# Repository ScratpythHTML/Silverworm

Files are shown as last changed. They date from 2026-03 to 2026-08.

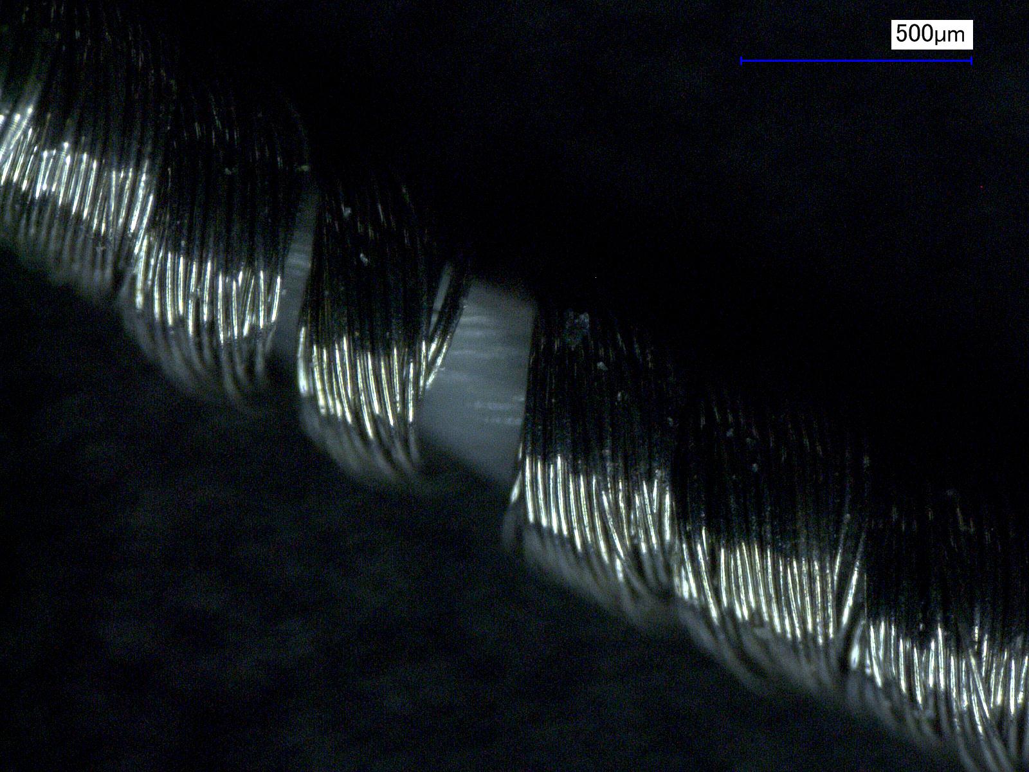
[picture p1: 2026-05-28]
image-processing/sample-images/Z150.jpg

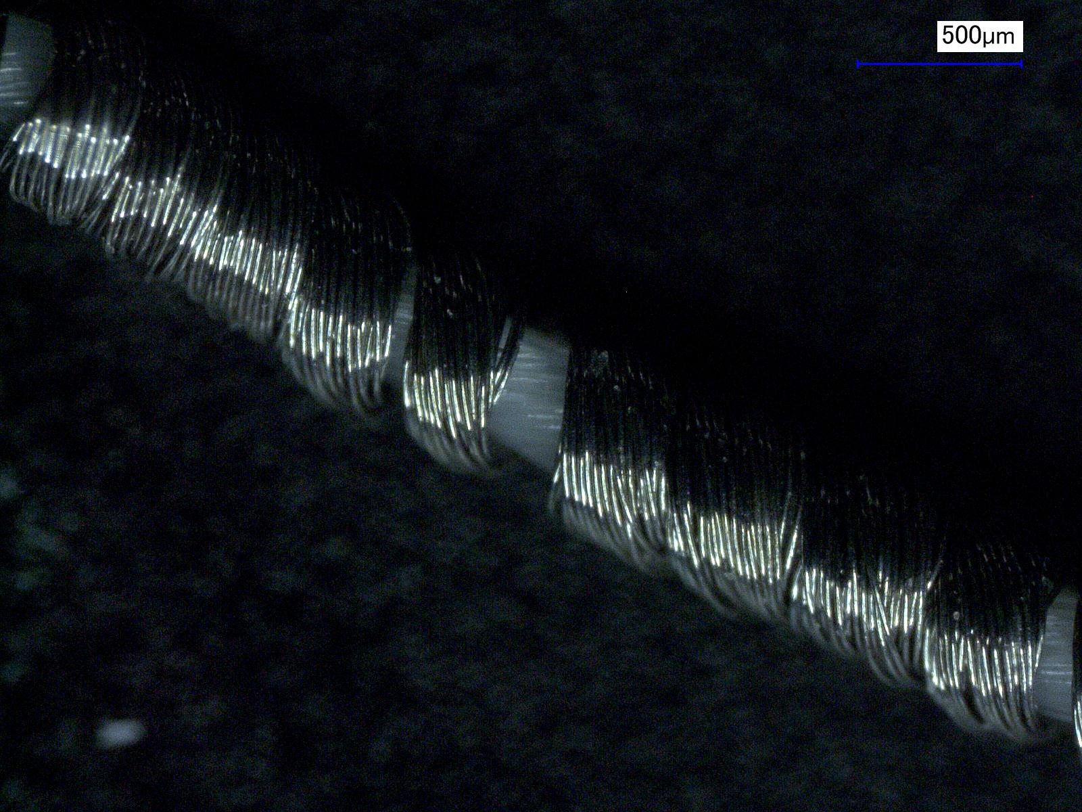
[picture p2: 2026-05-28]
image-processing/sample-images/Z100.jpg

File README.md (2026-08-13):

# Silverworm
Hardware and software design for the Silverworm spiral yarn wrapping machine.

## Group A
This is the wrapping team. We have designed a rotating arm that enscapulates a core yarn with a conductive outer fibre. The code in this repository is used to set the speed of the motor.

### Hardware
- Arduino Nano Every
- VNH5019 Motor Driver
- Honeywell Digital Hall Effect Sensor
- CHANCS 30W Permanent Magnet DC Motor 

### Software
The arduino code takes an inputted reference speed and accelerates the motor to this. It uses a Hall effect sensor and magnets on the arm to calculate the current speed. A PID controller is used for this system to eliminate error and ensure the motor willl get to the correct speed with in a set time. 

## Group B
This is the feeding. We have a feeding system that is passively tensioned which goes into team A's system; after the warpped yarn comes out, we collect it on a rotating collecting spool, which is on a linear rail to ensure orthodirectionality. 

### Hardware
- STM32
- DM423T Stepper Driver
- Linear Guide Rail with Nema 23 Stepper Motor
- oDrive S1 Motor Driver
- 24V 3000RPM 0.16Nm 50W 3.30A 42x42x62mm Brushless DC Motor ( with included hall effect sensor ) 
- 2 x Incremental Rotary Encoder IHC3808-001G-2000BZ1 ABZ 3-Channel 8mm Hollow Shaft

### Software
The code would take a inputted speed of the linear core yarn and then calculate the corresponding speeds that the linear rail and the BLDC motor would need to run at to ensure linear speed is accurate. The 2 encoders would give us both the radial velocity of the wrapper and the core yarn, allowing us to create a closed-loop control.

## Group C
This is the integration & control software — a PyQt6 app on a Raspberry Pi that reads the physical control panel, drives both motors, and measures yarn pitch live from a microscope camera.

### Hardware
- Raspberry Pi (Compute Module 5 + IO board)
- ESP32 physical UI panel — dials + mode/power switches (I2C)
- Wrap & feed motor controllers (SPI)
- AmScope HHD 8300-P USB microscope

### Software
The app is the system's central controller. It holds the machine state (mode, power, wrap + feed speeds), and the **physical panel is always the source of truth** — GUI controls are overwritten by the next dial/switch input. In AUTO it measures wrap pitch from the live camera and adjusts feed speed to hit the target; in MANUAL it overlays the target pitch/angle on the camera view for hand setup.

### Quick start

**On the wrapping machine (Raspberry Pi):**
```bash
python3 -m pip install -r interface/requirements-rpi.txt --break-system-packages
cd interface && python3 app.py
```

**On another computer (development, no hardware):**
```bash
python3 -m pip install -r interface/requirements.txt
cd interface && python3 app.py
```

On first launch you'll set target pitch, wire thickness, and tube diameter (tick "Remember settings" to skip it next time). With no panel attached, use the **Debug** menu to simulate dial/switch input.

### Code files
```
interface/
  app.py             Launcher — startup dialog → main window
  ui/main_window.py  Wires UI + state + hardware together
  app_state.py       Central state (mode/power/speeds), routes motor commands
  config.py          Settings, JSON persistence, wrap-angle math
  pitch_control.py   Closed-loop pitch → feed-speed control
  telemetry.py       Per-command timing/telemetry for the test report
  storage.py         Atomic saves (snapshots, recordings, logs)
  hardware.py        Picks real vs mock I2C/SPI transports per platform
  comms/
    pui.py           ESP32 panel protocol (I2C parser + listener)
    motor_spi.py     Arduino motor protocol (SPI packet codec)
  camera/            AmScope detection, capture, rolling frame buffer
  processing/
    pipeline.py      Runs pitch estimation on live camera frames
  ui/                GUI widgets (camera view, controls, graphs, dialogs)
  hil_test.py        Hardware-in-the-loop harness (no camera needed)
  diagnose.py        Environment / setup checker
image-processing/
  pitch_estimate.py  CV pitch measurement (OpenCV + SciPy)
```

### Continuing development
Start at `app.py` → `ui/main_window.py` → `app_state.py` (the central state machine). The reference sections below cover the protocols, formulas, and extension recipes you need to add features or bring up new hardware.

## How it works (reference)

### Architecture
```
ESP32 (panel) ──I2C──► Raspberry Pi (this app) ──SPI──► Arduino (motors)
 dials/switches          PyQt6 GUI + vision            wrap + feed
                         AppState = source of truth
```
The **physical panel always wins**: any dial/switch event overwrites what the GUI set. The GUI is a display/backup.

### Communication protocols
**I2C — panel → Pi (ASCII):**

| Message | Meaning |
|---|---|
| `D1±N` | Dial 1 (wrap) ± N detents, N∈{1,2,3} = small/med/large |
| `D2±N` | Dial 2 (feed) ± N detents |
| `AS0` / `AS1` | Mode → MANUAL / AUTO |
| `TP` | Toggle machine power |

Dials send *increments*, not absolute values; the detent→units lookup is in `DetentConfig` (`config.py`).

**SPI — Pi → Arduino (byte packets):**

| Prefix | Command | Payload |
|---|---|---|
| `0x01` | Start | speedL, speedH (uint16 LE) |
| `0x02` | Stop | stop_type (1=ramp, 2=emergency, 3=power-off) |
| `0x03` | Set speed | speedL, speedH |
| `0x04` | Test movement | movement_type |
| `0x05` | Request speed | — |

**SPI — Arduino → Pi:** `0x01` current speed · `0x02` error_code · `0x03` sequence status.

### Core formulas
```python
theta = arctan(pitch / (pi * (tube_diameter + 2 * wire_thickness)))  # wrap angle
pitches_um = np.diff(peak_positions_px) * um_per_px                   # pitch from peaks
cv = std_pitch / mean_pitch                                          # confidence:
#   HIGH if wraps>=10 and cv<0.20 ; MEDIUM if wraps>=5 and cv<0.35 ; else LOW
```

### Settings
Persisted to the OS config dir, loaded on startup (target pitch, wire thickness, tube diameter, detent→speed mappings, remember-settings): macOS `~/Library/Preferences/Silverworm/config.json`, Linux `~/.config/Silverworm/config.json`. The manual-mode GUI toggle is hidden by default (enable in Settings with the warning ack) to avoid PUI/GUI desync.

## Extending the app
- **New PUI message:** add a case in `parse_pui_message()` + a dataclass (`comms/pui.py`) → signal on `PUIListener` → `apply_*` handler on `AppState` → wire in `MainWindow._connect_app_state_signals()` → test in `tests/test_pui_protocol.py` + `tests/test_app_state.py`.
- **New motor command:** add to `CommandPrefix` + `build_<cmd>()` with bounds checks (`comms/motor_spi.py`) → method on `MotorController` → test in `tests/test_motor_spi.py`.
- **Tune pitch detection:** edit `image-processing/pitch_estimate.py` (`min_dist_px`, `sigma`, `prom_factor`).

## Testing
```bash
cd interface
pytest -q tests/test_pui_protocol.py tests/test_motor_spi.py tests/test_app_state.py
```
The protocol layer is fully tested without hardware via `MockPUITransport` / `MockSPITransport`. Camera/UI tests need Linux + `pytest-qt`.

## Repository map
Several subfolders have their own README with hardware-specific detail (pin maps, wiring, board files). Start here, then drill in:

| Folder | Contents |
|---|---|
| [interface/](interface/) | Group C control software (see above) |
| [image-processing/](image-processing/) | Pitch-measurement CV pipeline |
| [GroupA/](GroupA/) | Group A wrapper-motor firmware (Arduino Nano Every) |
| [GroupB/](GroupB/README.md) | Group B collecting firmware + Uno pin map |
| [IO Panel/](IO%20Panel/Silverworm_Control_Panel/README.md) | ESP32 panel pinout + I2C protocol |
| → [Web test tool](IO%20Panel/Silverworm_Control_Panel/IO%20Panel%20Software/Web_Test_Version/README.md) | Browser serial test UI for the panel |
| [Motherboard/Hardware/](Motherboard/Hardware/Silverworm%20-%20CM5%20Motherboard/) | CM5 carrier-board KiCAD files |
| [Motherboard/Software/](Motherboard/Software/README.md) | Enabling SPI/I2C on the CM5 |
| [Subsystem Interfacing/](Subsystem%20Interfacing/README.md) | Cross-board SPI wiring overview |

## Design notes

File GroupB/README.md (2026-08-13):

# Collecting-system firmware (Arduino Uno R2)

For **STM32CubeIDE** (bare metal), see `[stm32/motors/README.md](../../stm32/motors/README.md)`.

Target board: **Arduino Uno R2** (ATmega328P).

| Subsystem | Hardware | Interface |
| --- | --- | --- |
| Linear rail | FSK40J + NEMA 23 + **DM423T** | STEP / DIR / ENA → D2–D4 |
| Collecting spool | 42BSA62 + **oDrive S1** | UART → D8–D9; encoder **#1** on oDrive ENC0 |
| Line / roller shaft | IHC3808 encoder **#2** | Quadrature A/B/(Z) → D5–D7 |
| Supervisor | Raspberry Pi | SPI slave → D10–D13 |

No USB serial commands in production — control is **SPI only** (`SpiProtocol.h`).

## Uno pin map (ATmega328P)

| Arduino pin | ATmega328P port | Function |
| --- | --- | --- |
| D2 | PD2 | Linear STEP → DM423T PUL+ |
| D3 | PD3 | Linear DIR → DM423T DIR+ |
| D4 | PD4 | Linear ENA → DM423T ENA+ |
| D5 | PD5 | Encoder #2 A |
| D6 | PD6 | Encoder #2 B |
| D7 | PD7 | Encoder #2 Z (index, optional) |
| D8 | PB0 | oDrive UART RX ← oDrive TX |
| D9 | PB1 | oDrive UART TX → oDrive RX |
| D10 | PB2 | SPI SS (CS) ← Pi |
| D11 | PB3 | SPI MOSI ← Pi |
| D12 | PB4 | SPI MISO → Pi |
| D13 | PB5 | SPI SCK ← Pi |
| A0 | PC0 | Limit switch min (optional) |
| A1 | PC1 | Limit switch max (optional) |

DM423T **PUL−, DIR−, ENA−** → Arduino **GND**.

`config.h` uses Arduino pin numbers (`2`–`13`, `A0`/`A1`) as on the Uno.

## Power and grounds

- **24 V** → DM423T and oDrive motor supply (common GND).
- **5 V** → DM423T logic (if required), oDrive `ISO_VDD` (set logic level per [oDrive UART docs](https://docs.odriverobotics.com/v/latest/manual/uart.html)).
- Uno I/O is **5 V**. Level-shift SPI and UART to the Pi and oDrive if those interfaces expect 3.3 V.
- **Pi GND** ↔ Arduino GND.

## oDrive setup (ODrive Tool / Web GUI)

Before relying on firmware:

1. Motor phases → oDrive; **incremental encoder #1** on **ENC0** (A, B, Z).
2. Set `inc_encoder0.config.cpr` (typically **8000** for 2000 PPR quadrature).
3. Run encoder calibration and closed-loop test.
4. Enable UART A at `**ODRIVE_BAUD` (19200)**. Firmware uses **SoftwareSerial** on D8/D9 — the Uno has only one hardware UART (D0/D1, used by USB serial). To use hardware Serial instead, rewire to D0/D1 and switch `BldcMotor` to `HardwareSerial` (Serial).
5. Match GPIO UART pins on the S1 to your harness.
6. Optional: save `vel_ramp_rate` in the GUI if you tune ramping there — firmware also sets **velocity ramp** (`INPUT_MODE_VEL_RAMP`) at boot to match `SPI_SPEED_RAMP_RPM_S` in `config.h`.

Firmware uses the **[ODriveArduino](https://docs.odriverobotics.com/v/latest/guides/arduino-uart-guide.html)** library (`ODriveUART`: `setVelocity`, `getFeedback`, `clearErrors`, closed-loop state).

## Encoder #2

Counted in firmware via GPIO interrupts on D5 and D6 (PD5, PD6). `lineEncoder.rpm()` is updated in `poll()` for local use (ratio / monitoring). SPI telemetry prefix `'1'` still reports **spool** RPM from oDrive feedback.

Set `ENC2_CPR` in `config.h` to match the IHC3808 datasheet.

## SPI protocol

See `SpiProtocol.h` and the transaction rules in the previous sections of this README.

Outbound priority: **error** > **sequence ack** > **live spool speed**.

## Build

1. Install the **Arduino IDE** (2.x recommended) with the standard **Arduino AVR Boards** package.
2. Install **ODriveArduino**: *Sketch → Include Library → Manage Libraries* → "ODriveArduino".
3. Open `motors.ino`.
4. Board: **Arduino Uno** (Tools → Board → Arduino AVR Boards → Arduino Uno).
5. Edit `config.h` (stroke, CPR, limits).
6. Upload via USB.

## Calibration

1. Set `LINEAR_STROKE_MM_DEFAULT` to your FSK40J stroke.
2. Home linear axis (limits on A0/A1 when wired).
3. Confirm oDrive enters closed loop and spool feedback RPM matches direction before coupling yarn.

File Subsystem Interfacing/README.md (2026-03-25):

## SPI Protocol outline:



## SPI for Raspberry Pi:
Motherboard runs as Master
See Motherboard section.

## SPI on microcontrollers
The microcontrollers are set as slaves.

Read this guide for info: https://www.circuitbasics.com/how-to-set-up-spi-communication-for-arduino/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,to%20send%20or%20receive%20data.

Here are the docs for the `SPI.h` Arduino library: https://docs.arduino.cc/language-reference/en/functions/communication/SPI/

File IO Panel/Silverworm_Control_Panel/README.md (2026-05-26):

# UI Panel Pinout

| Pin | Use | Mode |
|---|---|---|
| GPIO 0  | LED1-R | ANALOG OUT |
| GPIO 1  | LED1-G | ANALOG OUT |
| GPIO 2  | LED1-B | ANALOG OUT |
| GPIO 3  | TOGGLE | DIG INPUT |
| GPIO 13 | BTN2_LED | NOT USED |
| GPIO 14 | BTN_1LED | DIGITAL OUT  |
| GPIO 4  | BTN2 | NOT USED |
| GPIO 5  | BTN1 | INPUT PULLUP |
| GPIO 24 | DIAL1A | DIG INPUT |
| GPIO 23 | DIAL1B | DIG INPUT |
| GPIO 10 | DIAL1NO  | INPUT PULLUP |
| GPIO 11 | DIAL2A | DIG INPUT |
| GPIO 25 | DIAL2B | DIG INPUT |
| GPIO 12 | DIAL2NO  | INPUT PULLUP |
| GPIO 8  | SDA | SDA |
| GPIO 22 | SCL | SCL |
| GPIO 9  | LED2-R | ANALOG OUT |
| GPIO 27 | LED2-G | ANALOG OUT |
| GPIO 26 | LED2-B | ANALOG OUT |

# UI Panel Communications Protocol:

Uses I2C for communications between the ESP32 and the RPi

On the RPi side, we are using pins:
GPIO10 for SDA
GPIO11 for SCL

## I2C Functions for Communication:

The ESP32 sends the change in speeds for the motors, which the Raspberry Pi then applies to the variables within the backend which store the target motor speeds

### For Dials:
The ESP32 sends the label `D1` or `D2` before every command to identify dials 1 and 2
Then the number that it increments by:
- Small detent gives a `+1` or `-1`
- Medium detent gives `+2` or `-2`
- Large detent gives `+3` or `-3`

_For example: `D1-2` or `D2+1`_

So the ESP32 tells the RPi _which_ detent option is being used, it is then up to the RPi to decide what this means with regards to motor speeds.
The user can decide what the increments are for each motor/dial combo.

### For the auto/manual switch:
The ESP32 sends the label `AS` before the argument
- It sends `0` if it is set to manual mode
- It sends `1` if it is set to automatic mode

So as soon as the RPi receives `AS0`, it sets the program to manual, regardless of what is already running on the machine. As soon as the RPi receives `AS1` it goes to automatic mode. The GUI still has the power to change the mode, but the signals received from the ESP32 always override the mode.

### For the ON/OFF switch:
The ESP sends a simple command `TP` which toggles the machine between the ON and OFF state.
The RPi sends `ON` or `OFF` to the ESP32 when it the machine starts and stops, so that the ESP can cotnrol the status light inside the power button.

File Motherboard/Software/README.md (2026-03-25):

# Motherboard - RPi CM5 - Software Setup

## How to enable SPI communication

[Taken from Sparkfun tutorial here](https://learn.sparkfun.com/tutorials/raspberry-pi-spi-and-i2c-tutorial/all)

1. Run `sudo raspi-config`
2. Select `5 Interfacing Options`
3. Select `P4 SPI`
4. Select yes when it asks you to enable SPI
5. Also select yes if it asks about automatically loading the kernel module.
6. Use the right arrow to select the `<Finish>` button.
7. Select yes when it asks to reboot.

8. After reebooting, run
```
ls /dev/*spi*
```

9. Expect the Pi to respond with a list of the enabled SPI pins (should be 6 pins on the CM5)

## Found this SPI comms article:
https://roboticsbackend.com/raspberry-pi-master-arduino-uno-slave-spi-communication-with-wiringpi/

## Protocol description:


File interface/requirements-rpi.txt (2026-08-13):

# Raspberry Pi install — everything needed to run on the device.
# One command installs the GUI/CV deps plus the hardware transports:
#   pip install -r interface/requirements-rpi.txt --break-system-packages
-r requirements.txt

# Hardware transports — need Linux kernel interfaces. On macOS, spidev cannot
# build because linux/spi/spidev.h is not available (hence the dev machine
# uses requirements.txt instead).
smbus2>=0.6.1; sys_platform == "linux"
spidev>=3.8; sys_platform == "linux"

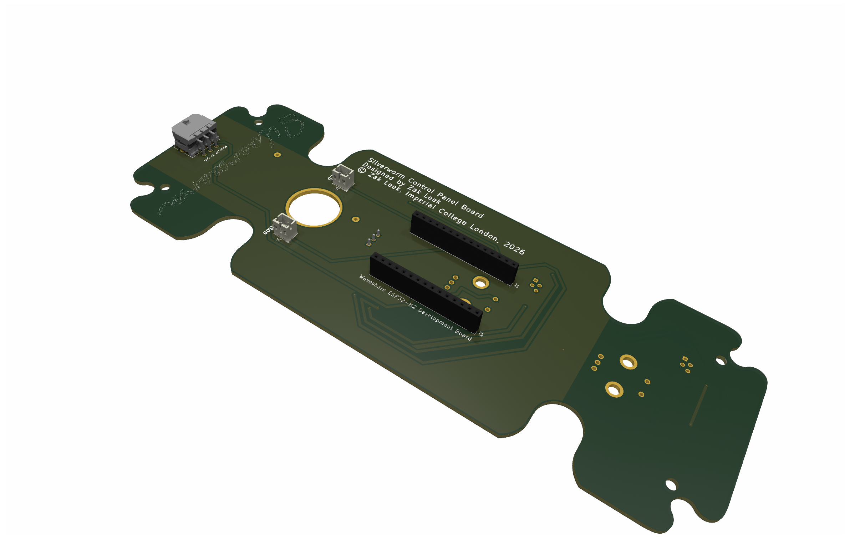
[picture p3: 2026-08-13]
IO Panel/Silverworm_Control_Panel/Control_Panel_3d_backside_iso.png

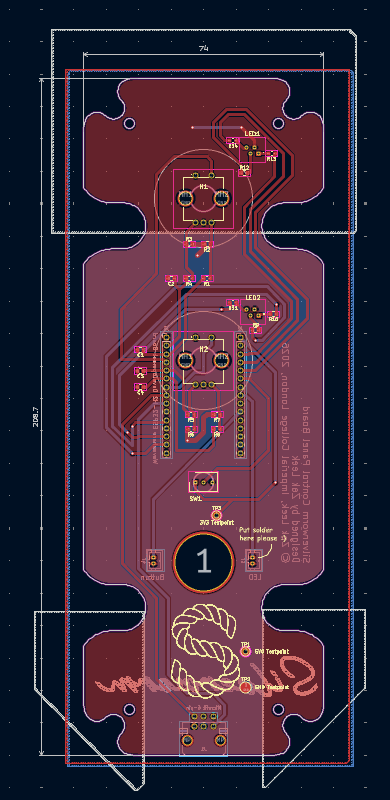
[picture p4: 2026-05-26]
IO Panel/Silverworm_Control_Panel/whole pcb cad.png

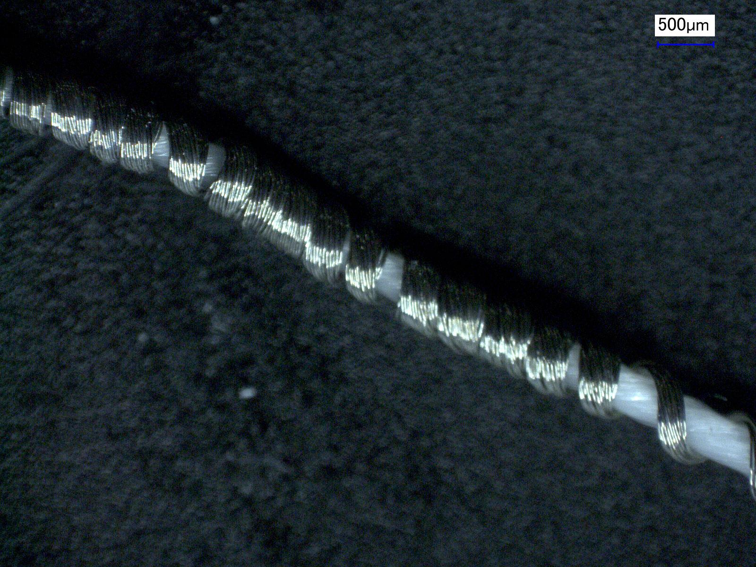
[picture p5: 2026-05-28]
image-processing/sample-images/Z50.jpg

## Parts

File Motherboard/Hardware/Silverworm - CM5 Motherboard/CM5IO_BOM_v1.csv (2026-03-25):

Reference | Value | Datasheet | Footprint | Qty | DNP | Field4 | Field5 | Field6 | Field7 | Field8 | Part Description | Farnell Price/Stock | Farnell Part Number
C1,C9,C12,C13,C18 | 100n | https://search.murata.co.jp/Ceramy/image/img/A01X/G101/ENG/GRM155R71C104KA88-01.pdf | Capacitor_SMD:C_0402_1005Metric | 5 |  | Farnell | 2611911 | RM EMK105 B7104KV-F | TAIYO YUDEN EUROPE GMBH | 110091611 | 0.1uF 10% 16V Ceramic Capacitor X7R 0402 (1005 Metric)
C2,C7,C8 | 10u | https://search.murata.co.jp/Ceramy/image/img/A01X/G101/ENG/GRM21BR71A106KA73-01.pdf | Capacitor_SMD:C_0805_2012Metric | 3 |  | Digikey | 490-14381-1-ND | GRM21BR71A106KA73L | Murata | 111893011 | 10uF 10% 10V Ceramic Capacitor X7R 0805 (2012 Metric)
C3 | 100uF | ~ | Capacitor_Tantalum_SMD:CP_EIA-7343-31_Kemet-D | 1 |  | Mouser | 667-EEF-CX0J101R |  | Panasonic |  | Capacitor, SP-Cap, 100u, 6.3V, 15mR ESR
D1 | LED Red | http://optoelectronics.liteon.com/upload/download/DS22-2000-210/LTST-S270KRKT.pdf | LED_SMD:LED_0603_1608Metric | 1 |  | Digikey | LTST-S270KRKT | SML-A12U8TT86Q | Rohm | 650295101 | Red 620nm LED Indication - Discrete 2.2V 2-SMD, No Lead
D2 | LED Green | http://optoelectronics.liteon.com/upload/download/DS22-2000-226/LTST-S270KGKT.pdf | LED_SMD:LED_0603_1608Metric | 1 |  | Digikey | LTST-S270KGKT | SML-A12M8TT86N | Rohm | 650263301 | Green 572nm LED Indication - Discrete 2.2V 2-SMD, No Lead
IC1 | CY7C65632-28LTXC | https://www.cypress.com/file/114101/download | CM5IO:QFN50P500X500X80-29N-D | 1
J1,J13 | USB_A_Stacked | ~ | CM5IO:57876171 | 2
J2 | Conn_02x07_Odd_Even | https://www.toby.co.uk/uploads/publications/1673.pdf | Connector_PinHeader_2.54mm:PinHeader_2x07_P2.54mm_Vertical | 1 |  | Toby | THD-07-R | THD-07-R | Toby |  | PinHeader_2x07_P2.54mm_Vertical
J5,J16 | Conn_01x22_Female | https://www.hirose.com/product/document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 | CM5IO:Hirose_FH12-22S-0.5SH_1x22-1MP_P0.50mm_Horizontal | 2 |  | Mouser | 798-FH12-22S-0.5SH55 | FH12-22S-0.5SH55 | Hirose |  | 22 Position FFC, FPC Connector Contacts, Bottom 0.020" (0.50mm) Surface Mount, Right Angle
J6,J9 | THD-02-R | https://www.toby.co.uk/uploads/publications/1673.pdf | Connector_PinHeader_2.54mm:PinHeader_2x02_P2.54mm_Vertical | 2 |  | Toby | THD-02-R | 151-604-425-761 | EDAC | UCON00791 | PinHeader_2x02_P2.54mm_Vertical
J7 | Microfit 6-pin | ~ | Connector_Molex:Molex_Micro-Fit_3.0_43045-0621_2x03-1MP_P3.00mm_Horizontal | 1
J8 | THD-20-R | https://www.toby.co.uk/uploads/publications/1673.pdf | Connector_PinHeader_2.54mm:PinHeader_2x20_P2.54mm_Vertical | 1 |  | Toby | THD-20-R | THD-20-R | Toby | UCON00511 | PinHeader_2x20_P2.54mm_Vertical
J10,J22 | 690-019-298-412 | https://www.tme.eu/Document/f15dffbcfad8545e17826f72d36911c8/206A-SEAN-R03.pdf | CM5IO:EDAC 690-019-298-412 | 2 |  | Farnell | 2614936 | 690-019-298-412 | EDAC | UCON00802 | HDMI Connector, Right Angle, 19 Contacts, Receptacle, Surface Mount, Surface Mount Right Angle
J11 | USB_C_Receptacle_USB2.0 | https://www.usb.org/sites/default/files/documents/usb_type-c.zip | Connector_USB:USB_C_Receptacle_GCT_USB4105-xx-A_16P_TopMnt_Horizontal | 1 |  |  | USBF31-0171 | USBF31-0171 | MTCONN |  | USBC USB2 data and power connector
J12 | USB3_A | ~ | CM5IO:MTCONN_UBAF30-D2011 | 1 |  |  | UBAF30-D2011 | UBAF30-D2011 | Mtconn |  | Dual USB 3 connector
J14 | JST_SHBM04B-SRSS-TB |  | Connector_JST:JST_SH_BM04B-SRSS-TB_1x04-1MP_P1.00mm_Vertical | 1 |  |  | SHBM04B-SRSS-TB | SHBM04B-SRSS-TB | JST |  | 4 pin vertical 1mm pitch connector
J15,J17,J19,J20 | Microfit 2-Pin | ~ |  | 4
J18 | JST-SM | ~ |  | 1
Module1 | ComputeModule5-CM5 |  | CM5IO:Raspberry-Pi-5-Compute-Module | 1 |  | Amphenol | 2x 10164227-1001A1RLF | 2x 10164227-1001A1RLF | Hirose |  | 100 Position Connector Receptacle, Center Strip Contacts Surface Mount Gold
R1,R10 | 1k | https://fscdn.rohm.com/en/products/databook/datasheet/passive/resistor/chip_resistor/mcr-e.pdf | Resistor_SMD:R_0402_1005Metric | 2 |  | Farnell | 9239235 | RK73H1ETTP1001F | KOA EUROPE GMBH | 125049511 | Resistor 1K M1005 1% 63mW
R2,R3 | 470R | https://fscdn.rohm.com/en/products/databook/datasheet/passive/resistor/chip_resistor/mcr-e.pdf | Resistor_SMD:R_0402_1005Metric | 2 |  | Farnell | 9239197 | RK73G1ETQTP4700D | KOA EUROPE GMBH | 120887981 | Resistor 470R M1005 1% 63mW
R5 | 0R | https://fscdn.rohm.com/en/products/databook/datasheet/passive/resistor/chip_resistor/mcr-e.pdf | Resistor_SMD:R_0805_2012Metric_Pad1.20x1.40mm_HandSolder | 1 |  | Farnell | 9233750 | MCR10EZPJ000 | Rohm | 121629591 | Resistor 0R M2012 5%
R6,R7,R8,R9 | 2.2K 1% | https://fscdn.rohm.com/en/products/databook/datasheet/passive/resistor/chip_resistor/mcr-e.pdf | Resistor_SMD:R_0402_1005Metric | 4 |  | Farnell |  |  |  |  | Resistor 2.2K M1005 1% 63mW
R11 | 10K 1% | https://fscdn.rohm.com/en/products/databook/datasheet/passive/resistor/chip_resistor/mcr-e.pdf | Resistor_SMD:R_0402_1005Metric | 1 |  | Farnell |  | MCR01MZPF1002 | Rohm |  | Resistor 10K M1005 1% 63mW
R12 | 15K 1% | https://fscdn.rohm.com/en/products/databook/datasheet/passive/resistor/chip_resistor/mcr-e.pdf | Resistor_SMD:R_0402_1005Metric | 1 |  | Farnell | 9239375 | MCR01MZPF1502 | Rohm | 120891581 | Resistor 15K M1005 1% 63mW
R13 | 470R | ~ |  | 1
R18,R19 | 5.1K | https://fscdn.rohm.com/en/products/databook/datasheet/passive/resistor/chip_resistor/mcr-e.pdf | Resistor_SMD:R_0402_1005Metric | 2 |  | Farnell |  |  |  |  | Resistor 2.2K M1005 1% 63mW
R20 | 649R | https://fscdn.rohm.com/en/products/databook/datasheet/passive/resistor/chip_resistor/mcr-e.pdf | Resistor_SMD:R_0402_1005Metric | 1 |  | Farnell | 9239197 | RK73G1ETQTP4700D | KOA EUROPE GMBH | 120887981 | Resistor 470R M1005 1% 63mW
R21,R22,R23,R24 | 10K | ~ |  | 4
SPI_1,SPI_3,SPI_5 | Minifit 2x4 | ~ | Connector_Molex:Molex_Mini-Fit_Jr_5569-08A2_2x04_P4.20mm_Horizontal | 3
SW1 | Right angle Tact button | https://www.mouser.co.uk/datasheet/2/240/Littelfuse-3050591.pdf | Button_Switch_THT:SW_Tactile_SPST_Angled_PTS645Vx58-2LFS | 1 |  |  | PTS645VH58-2LFS | PTS645VH58-2LFS | CK |  | Right angle through hole Tact switch
U1,U2 | TPD4EUSB30 | http://www.ti.com/lit/ds/symlink/tpd2eusb30a.pdf | Package_SON:USON-10_2.5x1.0mm_P0.5mm | 2 |  | Farnell | 2335455 | CDDFN10-3324P-13 | Bourns | UDIO00346 | Quad TVS diode for high speed signals (USB3, GigE etc.)
U3 | MagJack-A70-112-331N126 | https://p.globalsources.com/IMAGES/PDT/SPEC/690/K1160305690.pdf | CM5IO:TRJG0926HENL | 1 |  |  | TRJG0926HENL | TRJG0926HENL | Trxcon | UCON00900 | Gigabit Ethernet Magjack
U6 | AP22653W6 | https://www.diodes.com/assets/Datasheets/AP255x.pdf | Package_TO_SOT_SMD:SOT-23-6 | 1 |  | Digikey | 31-AP22653W6-7CT-ND | AP22653W6 | Diodes |  | Power Switch/Driver 1:1 P-Channel 2.1A SOT-23-6
U12 | RT9742SNGV | https://www.richtek.com/assets/product_file/RT9742/DS9742-10.pdf | Package_TO_SOT_SMD:TSOT-23_HandSoldering | 1 |  | Farnell | 2575555 | RT9742SNGV | RichTek | USWI00155 | Power Switch/Driver 1:1 N-Channel 500mA SOT-23-3

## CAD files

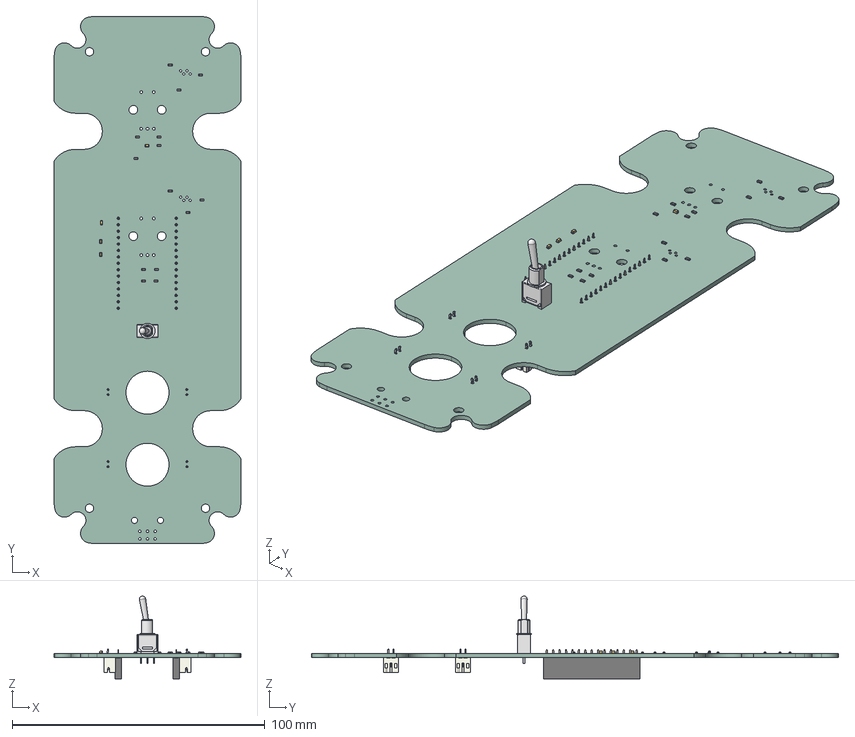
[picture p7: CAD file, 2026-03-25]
IO Panel/Silverworm_Control_Panel/Silverworm_Control_Panel.step
74.0 x 208.7 x 32.8 mm
R_0603_1608Metric x 14
CP_EIA-1608-10_AVX-L x 4
200MSP1T1B2M2QE
PinSocket_1x15_P2.54mm_Vertical x 2
JST_PH_B2B-PH-K_1x02_P2.00mm_Vertical x 4
Silverworm_Control_Panel_PCB

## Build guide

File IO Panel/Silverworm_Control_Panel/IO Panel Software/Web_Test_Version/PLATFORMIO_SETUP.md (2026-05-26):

# PlatformIO Setup for Silverworm Web Serial Control Panel

This guide explains how to set up and use this project with PlatformIO in VS Code.

## Project Structure

```
Web_Test_Version/
├── src/
│   └── main.cpp                 # Main firmware code
├── platformio.ini               # PlatformIO configuration
├── README.md                    # Usage guide
└── PLATFORMIO_SETUP.md         # This file
```

## Installation & Setup

### Step 1: Install PlatformIO in VS Code

1. Open VS Code
2. Go to Extensions (Ctrl+Shift+X)
3. Search for "PlatformIO IDE"
4. Click Install (by PlatformIO)
5. Wait for installation to complete and VS Code to reload

### Step 2: Open the Project

1. Open VS Code
2. File → Open Folder
3. Navigate to: `IO Panel/Silverworm_Control_Panel/IO Panel Software/Web_Test_Version/`
4. Click Select Folder

### Step 3: PlatformIO Will Auto-Configure

- PlatformIO reads `platformio.ini` automatically
- ArduinoJson library will auto-download
- This may take a few moments on first load

## Building & Uploading

### Build the Project

- Click the **✓ (Checkmark)** icon in the bottom toolbar, OR
- Use keyboard shortcut: `Ctrl+Alt+B`

### Upload to ESP32

1. Connect ESP32-H2 via USB cable
2. Click the **→ (Arrow)** icon in the bottom toolbar, OR
3. Use keyboard shortcut: `Ctrl+Alt+U`

### Serial Monitor

1. Click the **🔌 (Plug)** icon in the bottom toolbar, OR
2. Use keyboard shortcut: `Ctrl+Alt+S`
3. Baud rate should be **115200** (pre-configured)

## Troubleshooting

### "Board not found" or upload fails

1. Check USB cable connection
2. Verify ESP32 port is detected:
   - Windows: Device Manager → Ports (COM and LPT)
   - Linux/Mac: `ls /dev/tty*`
3. In VS Code, look for the port name
4. In `platformio.ini`, uncomment and set the correct port:
   ```ini
   monitor_port = COM3  ; Change to your port
   ```

### ArduinoJson not found

This means libraries aren't downloaded yet. Try:

1. Delete `.pio/` folder in the project
2. Click Build (Ctrl+Alt+B) to re-download dependencies
3. Wait for completion

### Upload hangs or fails

Try:

1. Press ESP32's **BOOT** button and hold while uploading
2. Or: Use Arduino IDE to verify the board works, then return to PlatformIO

### "Unknown board: esp32-h2-devkitm-1"

Update PlatformIO platform:

1. Open PlatformIO terminal (View → Terminal)
2. Run: `pio platform update espressif32`
3. Try building again

## PlatformIO Keyboard Shortcuts

| Action | Shortcut |
|---|---|
| Build | `Ctrl+Alt+B` |
| Upload | `Ctrl+Alt+U` |
| Serial Monitor | `Ctrl+Alt+S` |
| Build & Upload | `Ctrl+Alt+V` |
| Clean Build | `Ctrl+Alt+C` |
| PlatformIO Home | `Ctrl+Alt+H` |

## Using the Project

After successful upload:

1. Open Serial Monitor (Ctrl+Alt+S)
2. Wait for startup message: `"Waiting for serial connection..."`
3. Open the web interface HTML file in Chrome or Edge
4. Click "Connect to ESP32" button
5. Select the USB serial port when prompted
6. Control panel should become active!

## Modifying Code

- All firmware code is in `src/main.cpp`
- HTML/CSS/JavaScript is embedded in that file as a raw string
- After any changes, Build (Ctrl+Alt+B) and Upload (Ctrl+Alt+U)

## Extracting the HTML Interface

To create a standalone `index.html` file for quick access:

**From command line (Linux/Mac/Windows Git Bash):**
```bash
sed -n '/R"rawliteral(/,/)rawliteral"/p' src/main.cpp | head -n -1 | tail -n +2 > index.html
```

**Manual method:**
1. Open `src/main.cpp`
2. Find `const char INDEX_HTML[] PROGMEM = R"rawliteral(`
3. Copy everything until `);`
4. Remove the first and last lines
5. Save to `index.html`
6. Open in Chrome/Edge

## PlatformIO vs Arduino IDE

| Feature | PlatformIO | Arduino IDE |
|---|---|---|
| Dependency Management | ✅ Automatic | ❌ Manual |
| Multiple Boards | ✅ Excellent | ❌ Limited |
| Editor | VS Code | Basic |
| Build System | Scons | Make |
| Serial Monitor | ✅ Built-in | ✅ Built-in |

## Still Having Issues?

Try these diagnostic steps:

1. **In PlatformIO terminal:**
   ```bash
   pio device list          # See connected devices
   pio run -t monitor       # Start serial monitor
   pio run -t clean         # Clean build
   ```

2. **Check board detection:**
   - Plug/unplug USB while terminal is open
   - You should see COM port appear/disappear

3. **Verify environment:**
   - Open PlatformIO Home (Ctrl+Alt+H)
   - Check "Platforms" section for "Espressif 32"

## Web Serial API Browser Support

For the web interface to work, you need a browser that supports Web Serial API:

- ✅ Chrome/Chromium (all platforms)
- ✅ Edge (all platforms)
- ✅ Opera (all platforms)
- ❌ Safari (not supported)
- ❌ Firefox (not supported - under development)

## For More Help

- PlatformIO Docs: https://docs.platformio.org
- ESP32-H2 Board: https://docs.platformio.org/en/latest/boards/espressif32/esp32-h2-devkitm-1.html
- VS Code Help: https://code.visualstudio.com/docs
- Web Serial API: https://developer.mozilla.org/en-US/docs/Web/API/Web_Serial_API

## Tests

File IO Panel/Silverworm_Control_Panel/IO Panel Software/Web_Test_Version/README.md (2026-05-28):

# Silverworm Control Panel - Web Serial Test Version

This is a web-based testing interface for the Silverworm ESP32-H2 control panel using **Web Serial API**. It allows you to test the control panel functionality via USB serial connection with a beautiful graphical interface running in your browser.

## Features

- **USB Serial Connection**: Connect ESP32-H2 to laptop via USB cable
- **Web Interface**: Graphical control panel running in Chrome/Edge browser
- **Web Serial API**: Browser communicates with ESP32 over USB serial
- **Round Dials**: Swipe up/down to control dials with ±1/±2/±3 increments
- **RGB LED Control**: Tap colored circles to cycle through detent modes (Large/Medium/Small)
- **Real I2C Communication**: All commands sent to Raspberry Pi via I2C
- **Power LED Status**: Receives ON/OFF status from Raspberry Pi and displays in real-time

## Setup Instructions

### 1. Install Required Libraries

**For Arduino IDE:**
- Sketch → Include Library → Manage Libraries
- Search "ArduinoJson" and install latest version

**For PlatformIO:**
- Libraries auto-download from platformio.ini

### 2. Load the Firmware

**Arduino IDE:**
1. Open `Control_panel_web_version.ino`
2. Select Board: **ESP32-H2** (Tools → Board → ESP32 → ESP32-H2)
3. Select Port: (your ESP32 COM port)
4. Upload (Ctrl+U)

**PlatformIO:**
1. Open the `Web_Test_Version` folder in VS Code
2. Click Build (Ctrl+Alt+B)
3. Connect ESP32 and click Upload (Ctrl+Alt+U)

### 3. Connect and Use

1. **Connect via USB**: Plug ESP32-H2 into your Windows/Mac/Linux laptop via USB cable
2. **Open Browser**: Open the `index.html` file in Chrome, Edge, or Opera browser
3. **Click Connect**: Press the "Connect to ESP32" button
4. **Select Port**: Browser will show available serial ports - select the ESP32
5. **Use Interface**: Control the panel with swipes and taps

## Usage

### Dials (Dial 1 & Dial 2)

- **Swipe Up**: Rotates dial clockwise, sends positive increment command
- **Swipe Down**: Rotates dial counter-clockwise, sends negative increment command
- **Tap LED Circle**: Cycles through detent modes:
  - 🟢 **Green (Large)**: Each swipe = ±3 increment
  - 🟡 **Yellow (Medium)**: Each swipe = ±2 increment
  - 🔴 **Red (Small)**: Each swipe = ±1 increment

### Toggle Switch

- **Manual**: Sends `AS0` command to Raspberry Pi
- **Auto**: Sends `AS1` command to Raspberry Pi

### Power Button

- **Tap**: Sends `TP` (toggle power) command to Raspberry Pi
- **LED Indicator**: Shows ON/OFF status received from Raspberry Pi

## I2C Communication

The web interface sends the same I2C commands as the physical hardware:

| Command | Format | Example | Function |
|---|---|---|---|
| Dial Change | `D[1-2][+/-][1-3]` | `D1+3`, `D2-1` | Dial control |
| Mode Switch | `AS[0-1]` | `AS0`, `AS1` | 0=Manual, 1=Automatic |
| Power Toggle | `TP` | `TP` | Toggle power ON/OFF |
| Power Status | `ON` or `OFF` | `ON` | Received from RPi |

## Serial Communication Protocol

**Browser → ESP32 (JSON over serial):**
```json
{"type": "dial_swipe", "dial": 1, "direction": "up"}
{"type": "led_tap", "dial": 1}
{"type": "button", "button": "power"}
{"type": "toggle", "mode": "auto"}
```

**ESP32 → Browser (JSON over serial):**
```json
{"type": "power_led_status", "state": "on"}
{"type": "power_led_status", "state": "off"}
```

## Browser Compatibility

- ✅ **Windows**: Chrome, Edge, Opera
- ✅ **Mac**: Chrome, Edge, Opera
- ✅ **Linux**: Chrome, Edge, Opera
- ❌ **Safari**: Does not support Web Serial API
- ❌ **Firefox**: Does not support Web Serial API (yet)

**Recommended: Chrome or Edge on Windows**

## Troubleshooting

### "Serial port not found"
- Ensure USB cable is connected
- Check Device Manager (Windows) or System Report (Mac) for COM port
- Restart the ESP32 (press EN button)

### "Connect button doesn't work"
- Verify you're using Chrome, Edge, or Opera
- Try a different USB cable
- Check that browser is running on localhost or HTTPS

### No response when clicking buttons
- Check serial monitor (115200 baud) for debug messages
- Verify I2C connection to Raspberry Pi
- Check that Raspberry Pi is configured as I2C master

### HTML file won't open
- Make sure you're using Web Serial API supported browser
- For offline use, save the HTML file locally and open it with `file://` protocol (most browsers support this)

## Serial Monitor Debugging

Open the serial monitor at **115200 baud** to see:
- Connection messages from ESP32
- I2C commands being sent to Raspberry Pi
- Status updates received from Raspberry Pi

Example output:
```
=== Silverworm Web Serial Control Panel ===
Waiting for serial connection...
Open the HTML interface in Chrome/Edge and click 'Connect to ESP32'
I2C Command: D1+3
I2C Command: TP
```

## File Structure

```
Web_Test_Version/
├── Control_panel_web_version.ino      # Arduino IDE version
├── src/main.cpp                       # PlatformIO version
├── platformio.ini                     # PlatformIO config
├── index.html                         # Web interface (save this locally)
├── README.md                          # This file
└── PLATFORMIO_SETUP.md               # PlatformIO setup guide
```

## Creating a Standalone HTML File

To use the interface offline, extract the HTML from the .ino or .cpp file and save as `index.html`:

1. Open `Control_panel_web_version.ino`
2. Copy everything between `R"rawliteral(` and `)rawliteral"`
3. Save to a file named `index.html`
4. Open in Chrome/Edge browser

Or use this command:
```bash
sed -n '/R"rawliteral(/,/)rawliteral"/p' Control_panel_web_version.ino | head -n -1 | tail -n +2 > index.html
```

## Performance

- Communication: Serial at 115200 baud
- Latency: ~10-50ms per command
- I2C commands are queued and sent when Raspberry Pi requests them

## Original Hardware Version

The original hardware-based version (with physical encoders and buttons) is at:
```
IO Panel/Silverworm_Control_Panel/IO Panel Software/Control_panel.ino
```

## License

Same as parent Silverworm project.

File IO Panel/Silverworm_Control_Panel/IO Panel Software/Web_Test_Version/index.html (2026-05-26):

SILVERWORM

Connect to ESP32

Disconnected

DIAL 1

DIAL 2

MANUAL AUTO

①

Connect to begin

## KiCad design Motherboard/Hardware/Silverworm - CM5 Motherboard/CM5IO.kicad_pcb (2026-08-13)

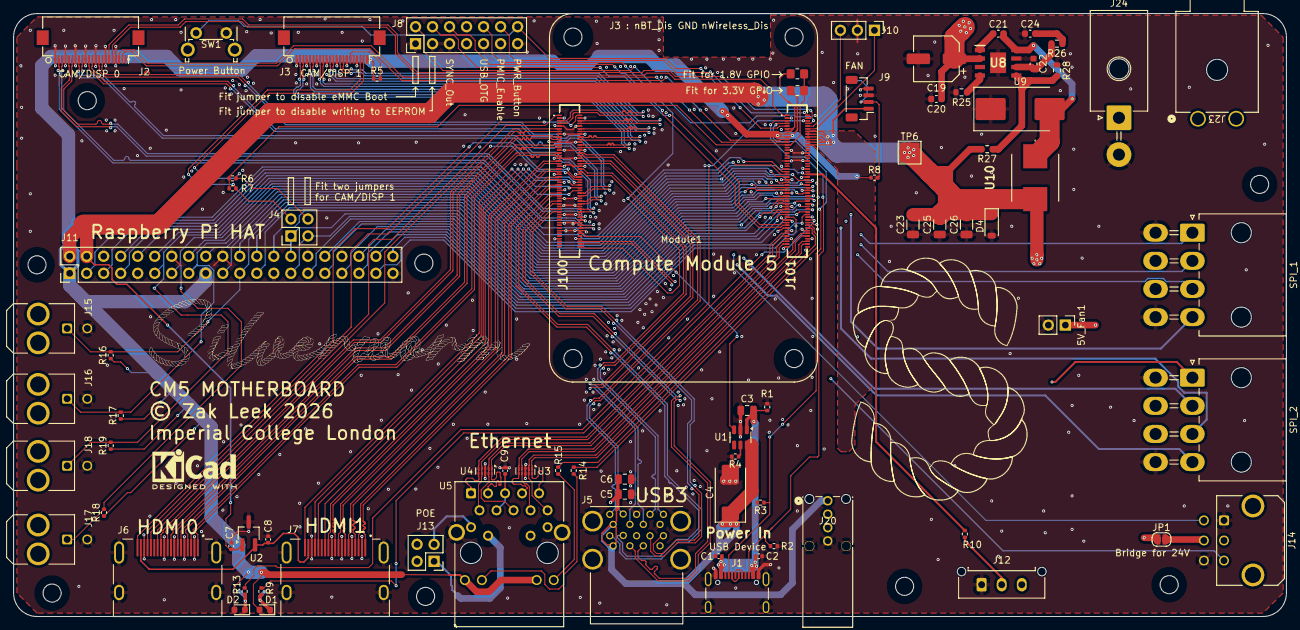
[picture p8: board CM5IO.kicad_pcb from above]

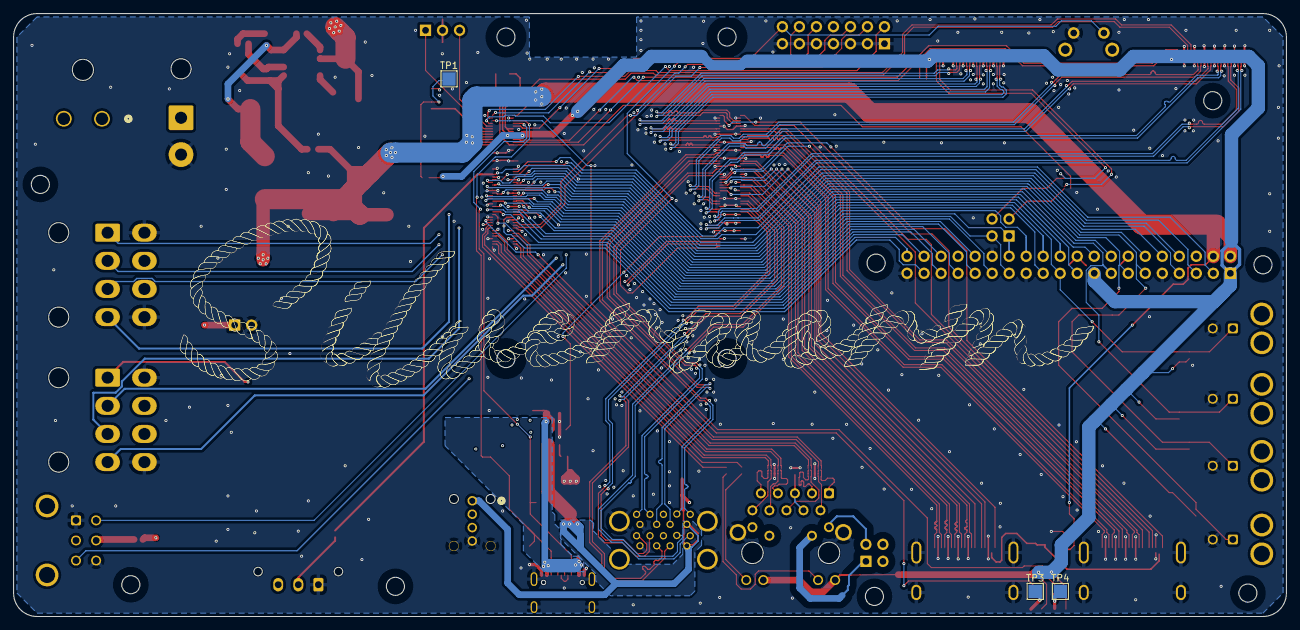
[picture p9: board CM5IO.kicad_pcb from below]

Board: 4 copper layers, 190.0 x 90.0 mm, 92 parts (3 on the bottom side), 148 nets.

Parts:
5V_Fan1: 1x2 Pin Header; PinHeader_1x02_P2.54mm_Vertical
C1, C2, C7, C8, C9: 100n; C_0402_1005Metric
C3, C5, C6: 10u; C_0805_2012Metric
C4: 100uF; CP_EIA-7343-31_Kemet-D
C19: GVT1J476M0608CNVC; CP_Elec_6.3x7.7
C20, C21: 100nF; C_0603_1608Metric
C22: 68pF; C_0603_1608Metric
C23, C25, C26: 47uF; C_1206_3216Metric
C24: 22nF; C_0603_1608Metric
D1: LED Green; LED_0603_1608Metric
D2: LED Red; LED_0603_1608Metric
D4: SMFJ5.0A; D_SOD-123
H1, H2, H3, H4, H5, H6, H7, H8: MountingHole; MountingHole_2.7mm_M2.5_DIN965
J1: USB_C_Receptacle_USB2.0; USB_C_Receptacle_GCT_USB4105-xx-A_16P_TopMnt_Horizontal
J2, J3: Conn_01x22_Female; Hirose_FH12-22S-0.5SH_1x22-1MP_P0.50mm_Horizontal
J4, J13: THD-02-R; PinHeader_2x02_P2.54mm_Vertical
J5: USB3_A; MTCONN_UBAF30-D2011
J6, J7: 690-019-298-412; EDAC 690-019-298-412
J8: Conn_02x07_Odd_Even; PinHeader_2x07_P2.54mm_Vertical
J9: JST_SHBM04B-SRSS-TB; JST_SH_BM04B-SRSS-TB_1x04-1MP_P1.00mm_Vertical
J10: Conn_01x03; PinHeader_1x03_P2.54mm_Vertical
J11: THD-20-R; PinHeader_2x20_P2.54mm_Vertical
J12: Microfit 3-pin; Molex_Micro-Fit_3.0_43650-0315_1x03_P3.00mm_Vertical
J14: Microfit 6-pin; Molex_Micro-Fit_3.0_43045-0621_2x03-1MP_P3.00mm_Horizontal
J15, J16, J17, J18: Microfit 2-Pin; Molex_Micro-Fit_3.0_43045-0221_2x01-1MP_P3.00mm_Horizontal
J20: USB_A; CONN_48204-0001_MOL
J23: Mega-Fit-1row-2pin; CONN_2002412000_02_MOL
J24: Mega-Fit-2row-2pin; Molex_Mega-Fit_76825-0002_2x01_P5.70mm_Horizontal
J100, J101: 101642271001A1RLF
JP1: Jumper_2_Open; SolderJumper-2_P1.3mm_Open_RoundedPad1.0x1.5mm
Module1: ComputeModule5-CM5; Raspberry-Pi-5-Compute-Module
R1, R5, R6, R7: 2.2K 1%; R_0402_1005Metric
R2, R3: 5.1K; R_0402_1005Metric
R4: 15K 1%; R_0402_1005Metric
R8: 10K 1%; R_0402_1005Metric
R9, R13: 1k; R_0402_1005Metric
R10, R14, R15: 470R; R_0402_1005Metric
R11: 0R; R_0805_2012Metric_Pad1.20x1.40mm_HandSolder
R12: nf; R_0805_2012Metric_Pad1.20x1.40mm_HandSolder
R16, R17, R18, R19: 10K; R_0402_1005Metric
R25: 120k; R_0603_1608Metric
R26, R28: 10k; R_0603_1608Metric
R27: 51k; R_0603_1608Metric
SPI_1, SPI_2: Minifit 2x4; Molex_Mini-Fit_Jr_5569-08A2_2x04_P4.20mm_Horizontal
SW1: Right angle Tact button; SW_Tactile_SPST_Angled_PTS645Vx58-2LFS
TP1, TP3, TP4: TestPoint; TestPoint_Pad_2.0x2.0mm
TP6: +5V; TestPoint_Pad_3.0x3.0mm
U1: AP22653W6; SOT-23-6
U2: RT9742SNGV; TSOT-23_HandSoldering
U3, U4: TPD4EUSB30; USON-10_2.5x1.0mm_P0.5mm
U5: MagJack-A70-112-331N126; TRJG0926HENL
U8: TPS54560DDAR; SOIC127P600X170-9N
U9: SS54; D_SMC_Handsoldering
U10: 10uH; ETQP5M_YFM

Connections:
24V_INPUT: J23.1, J24.1
+5V: 5V_Fan1.1, C1.1, C2.1, C3.1, C7.1, C23.2, C25.2, C26.2, D4.1 (K), J1.A4 (VBUS), J1.A9 (VBUS), J1.B4 (VBUS), J1.B9 (VBUS), J9.1, J11.2, J11.4, J12.3, J14.2, Module1.77 (+5v_(Input)), Module1.79 (+5v_(Input)), Module1.81 (+5v_(Input)), Module1.83 (+5v_(Input)), Module1.85 (+5v_(Input)), Module1.87 (+5v_(Input)), R1.2, R27.2, SPI_1.7, SPI_2.7, TP6.1, U1.1 (IN), U2.1 (IN), U10.2
+24V: C19.1, C20.1, J23.2, JP1.1 (A), SPI_1.6, SPI_2.6, U8.2 (VIN)
/+3.3v: D1.2 (A), D2.2 (A), J11.1, J11.17, Module1.84 (+3.3v_(Output)), Module1.86 (+3.3v_(Output)), R8.1, R11.1, R16.1, R17.1, R18.1, R19.1, U5.15 (LEDY_A), U5.17 (LEDG_A)
/CC1: J1.A5 (CC1), Module1.94 (CC1), R3.1
/CC2: J1.B5 (CC2), Module1.96 (CC2), R2.1
/CM5_GPIO ( Ethernet, GPIO, SDCARD)/+1.8v: Module1.88 (+1.8v_(Output)), Module1.90 (+1.8v_(Output)), R12.1
/CM5_GPIO ( Ethernet, GPIO, SDCARD)/BT_nDis: J10.3, Module1.91 (BT_nDisable)
/CM5_GPIO ( Ethernet, GPIO, SDCARD)/CAM_GPIO0: J2.17, Module1.97 (CAM_GPIO0)
/CM5_GPIO ( Ethernet, GPIO, SDCARD)/CAM_GPIO1: J2.18, Module1.100 (CAM_GPIO1)
/CM5_GPIO ( Ethernet, GPIO, SDCARD)/CSn_1: Module1.49 (GPIO18), SPI_1.4
/CM5_GPIO ( Ethernet, GPIO, SDCARD)/CSn_3: Module1.54 (GPIO4), SPI_2.4
/CM5_GPIO ( Ethernet, GPIO, SDCARD)/EEPROM_nWP: J8.4, Module1.20 (EEPROM_nWP)
/CM5_GPIO ( Ethernet, GPIO, SDCARD)/ETH_LEDG: Module1.17 (Ethernet_nLED2(3.3v)), R14.2
/CM5_GPIO ( Ethernet, GPIO, SDCARD)/ETH_LEDY: Module1.15 (Ethernet_nLED3(3.3v)), R15.2
/CM5_GPIO ( Ethernet, GPIO, SDCARD)/GPIO2: J11.3, Module1.58 (GPIO2)
/CM5_GPIO ( Ethernet, GPIO, SDCARD)/GPIO3: J11.5, Module1.56 (GPIO3)
/CM5_GPIO ( Ethernet, GPIO, SDCARD)/GPIO8: J11.24, Module1.39 (GPIO8)
/CM5_GPIO ( Ethernet, GPIO, SDCARD)/GPIO9: J11.21, J15.1, Module1.40 (GPIO9), R16.2
/CM5_GPIO ( Ethernet, GPIO, SDCARD)/GPIO10: J11.19, J14.4, Module1.44 (GPIO10)
/CM5_GPIO ( Ethernet, GPIO, SDCARD)/GPIO11: J11.23, J14.3, Module1.38 (GPIO11)
/CM5_GPIO ( Ethernet, GPIO, SDCARD)/GPIO12: J11.32, Module1.31 (GPIO12)
/CM5_GPIO ( Ethernet, GPIO, SDCARD)/GPIO13: J11.33, Module1.28 (GPIO13)
/CM5_GPIO ( Ethernet, GPIO, SDCARD)/GPIO15: J11.10, Module1.51 (GPIO15)
/CM5_GPIO ( Ethernet, GPIO, SDCARD)/GPIO16: J11.36, Module1.29 (GPIO16)
/CM5_GPIO ( Ethernet, GPIO, SDCARD)/GPIO23: J11.16, Module1.47 (GPIO23)
/CM5_GPIO ( Ethernet, GPIO, SDCARD)/GPIO24: J11.18, Module1.45 (GPIO24)
/CM5_GPIO ( Ethernet, GPIO, SDCARD)/GPIO25: J11.22, Module1.41 (GPIO25)
/CM5_GPIO ( Ethernet, GPIO, SDCARD)/GPIO26: J11.37, Module1.24 (GPIO26)
/CM5_GPIO ( Ethernet, GPIO, SDCARD)/GPIO_VREF: Module1.78 (GPIO_VREF(1.8v/3.3v_Input)), R6.1, R7.1, R11.2, R12.2
/CM5_GPIO ( Ethernet, GPIO, SDCARD)/ID_SC: J4.1, J11.28, Module1.35 (ID_SC)
/CM5_GPIO ( Ethernet, GPIO, SDCARD)/ID_SD: J4.3, J11.27, Module1.36 (ID_SD)
/CM5_GPIO ( Ethernet, GPIO, SDCARD)/LED_DATA: Module1.55 (GPIO14), R10.1
/CM5_GPIO ( Ethernet, GPIO, SDCARD)/LK_2: J16.1, Module1.46 (GPIO22), R17.2
/CM5_GPIO ( Ethernet, GPIO, SDCARD)/LK_3: J17.1, Module1.48 (GPIO27), R18.2
/CM5_GPIO ( Ethernet, GPIO, SDCARD)/LK_4: J18.1, Module1.50 (GPIO17), R19.2
/CM5_GPIO ( Ethernet, GPIO, SDCARD)/MISO_1: Module1.26 (GPIO19), SPI_1.2
/CM5_GPIO ( Ethernet, GPIO, SDCARD)/MISO_3: Module1.34 (GPIO5), SPI_2.2
/CM5_GPIO ( Ethernet, GPIO, SDCARD)/MOSI_1: Module1.27 (GPIO20), SPI_1.1
/CM5_GPIO ( Ethernet, GPIO, SDCARD)/MOSI_3: Module1.30 (GPIO6), SPI_2.1
/CM5_GPIO ( Ethernet, GPIO, SDCARD)/PMIC_ENABLE: J8.12, Module1.99 (PMIC_ENABLE)
/CM5_GPIO ( Ethernet, GPIO, SDCARD)/PWM: J9.2, Module1.19 (FAN_PWM), R8.2, TP1.1
/CM5_GPIO ( Ethernet, GPIO, SDCARD)/PWR_BUT: J8.14, Module1.92 (PWR_BUT), SW1.1
/CM5_GPIO ( Ethernet, GPIO, SDCARD)/SCLK_1: Module1.25 (GPIO21), SPI_1.3
/CM5_GPIO ( Ethernet, GPIO, SDCARD)/SCLK_3: Module1.37 (GPIO7), SPI_2.3
/CM5_GPIO ( Ethernet, GPIO, SDCARD)/SYNC_OUT: J8.6, Module1.18 (Ethernet_SYNC_OUT(3.3v))
/CM5_GPIO ( Ethernet, GPIO, SDCARD)/TACHO: J9.4, Module1.16 (FAN_TACHO)
/CM5_GPIO ( Ethernet, GPIO, SDCARD)/TR0_TAP: J13.3, U5.11 (VC1)
/CM5_GPIO ( Ethernet, GPIO, SDCARD)/TR1_TAP: J13.1, U5.12 (VC2)
/CM5_GPIO ( Ethernet, GPIO, SDCARD)/TR2_TAP: J13.2, U5.13 (VC3)
/CM5_GPIO ( Ethernet, GPIO, SDCARD)/TR3_TAP: J13.4, U5.14 (VC4)
/CM5_GPIO ( Ethernet, GPIO, SDCARD)/TRD0_N: Module1.10 (Ethernet_Pair0_N), U4.4 (D2+), U4.7, U5.2 (TRD0-)
/CM5_GPIO ( Ethernet, GPIO, SDCARD)/TRD0_P: Module1.12 (Ethernet_Pair0_P), U4.5 (D2-), U4.6, U5.1 (TRD0+)
/CM5_GPIO ( Ethernet, GPIO, SDCARD)/TRD1_N: Module1.6 (Ethernet_Pair1_N), U4.2 (D1-), U4.9, U5.6 (TRD1-)
/CM5_GPIO ( Ethernet, GPIO, SDCARD)/TRD1_P: Module1.4 (Ethernet_Pair1_P), U4.1 (D1+), U4.10, U5.3 (TRD1+)
/CM5_GPIO ( Ethernet, GPIO, SDCARD)/TRD2_N: Module1.9 (Ethernet_Pair2_N), U3.4 (D2+), U3.7, U5.8 (TRD2-)
/CM5_GPIO ( Ethernet, GPIO, SDCARD)/TRD2_P: Module1.11 (Ethernet_Pair2_P), U3.5 (D2-), U3.6, U5.7 (TRD2+)
/CM5_GPIO ( Ethernet, GPIO, SDCARD)/TRD3_N: Module1.5 (Ethernet_Pair3_N), U3.2 (D1-), U3.9, U5.10 (TRD3-)
/CM5_GPIO ( Ethernet, GPIO, SDCARD)/TRD3_P: Module1.3 (Ethernet_Pair3_P), U3.1 (D1+), U3.10, U5.9 (TRD3+)
/CM5_GPIO ( Ethernet, GPIO, SDCARD)/USBOTG: J8.10, Module1.101 (USB_OTG_ID)
/CM5_GPIO ( Ethernet, GPIO, SDCARD)/WL_nDis: J10.1, Module1.89 (WiFi_nDisable)
/CM5_GPIO ( Ethernet, GPIO, SDCARD)/nPWR_LED: Module1.95 (LED_nPWR), R13.2
/CM5_GPIO ( Ethernet, GPIO, SDCARD)/nRPIBOOT: J8.2, Module1.93 (nRPIBOOT)
/CM5_HighSpeed/+3.3v: J2.22, J3.22, R5.1
/CM5_HighSpeed/DPHY0_C_N: J2.8, Module1.127 (MIPI0_C_N)
/CM5_HighSpeed/DPHY0_C_P: J2.9, Module1.129 (MIPI0_C_P)
/CM5_HighSpeed/DPHY0_D0_N: J2.2, Module1.115 (MIPI0_D0_N)
/CM5_HighSpeed/DPHY0_D0_P: J2.3, Module1.117 (MIPI0_D0_P)
/CM5_HighSpeed/DPHY0_D1_N: J2.5, Module1.121 (MIPI0_D1_N)
/CM5_HighSpeed/DPHY0_D1_P: J2.6, Module1.123 (MIPI0_D1_P)
/CM5_HighSpeed/DPHY0_D2_N: J2.11, Module1.133 (MIPI0_D2_N)
/CM5_HighSpeed/DPHY0_D2_P: J2.12, Module1.135 (MIPI0_D2_P)
/CM5_HighSpeed/DPHY0_D3_N: J2.14, Module1.139 (MIPI0_D3_N)
/CM5_HighSpeed/DPHY0_D3_P: J2.15, Module1.141 (MIPI0_D3_P)
/CM5_HighSpeed/DPHY1_C_N: J3.8, Module1.187 (MIPI1_C_N)
/CM5_HighSpeed/DPHY1_C_P: J3.9, Module1.189 (MIPI1_C_P)
/CM5_HighSpeed/DPHY1_D0_N: J3.2, Module1.175 (MIPI1_D0_N)
/CM5_HighSpeed/DPHY1_D0_P: J3.3, Module1.177 (MIPI1_D0_P)
/CM5_HighSpeed/DPHY1_D1_N: J3.5, Module1.181 (MIPI1_D1_N)
/CM5_HighSpeed/DPHY1_D1_P: J3.6, Module1.183 (MIPI1_D1_P)
/CM5_HighSpeed/DPHY1_D2_N: J3.11, Module1.193 (MIPI1_D2_N)
/CM5_HighSpeed/DPHY1_D2_P: J3.12, Module1.195 (MIPI1_D2_P)
/CM5_HighSpeed/DPHY1_D3_N: J3.14, Module1.194 (MIPI1_D3_N)
/CM5_HighSpeed/DPHY1_D3_P: J3.15, Module1.196 (MIPI1_D3_P)
/CM5_HighSpeed/HDMI0_CEC: J6.13 (CEC), Module1.151 (HDMI0_CEC)
/CM5_HighSpeed/HDMI0_CK_N: J6.12 (CK-), Module1.190 (HDMI0_CLK_N)
/CM5_HighSpeed/HDMI0_CK_P: J6.10 (CK+), Module1.188 (HDMI0_CLK_P)
/CM5_HighSpeed/HDMI0_D0_N: J6.9 (D0-), Module1.184 (HDMI0_TX0_N)
/CM5_HighSpeed/HDMI0_D0_P: J6.7 (D0+), Module1.182 (HDMI0_TX0_P)
/CM5_HighSpeed/HDMI0_D1_N: J6.6 (D1-), Module1.178 (HDMI0_TX1_N)
/CM5_HighSpeed/HDMI0_D1_P: J6.4 (D1+), Module1.176 (HDMI0_TX1_P)
/CM5_HighSpeed/HDMI0_D2_N: J6.3 (D2-), Module1.172 (HDMI0_TX2_N)
/CM5_HighSpeed/HDMI0_D2_P: J6.1 (D2+), Module1.170 (HDMI0_TX2_P)
/CM5_HighSpeed/HDMI0_HOTPLUG: J6.19 (HPD/HEAC-), Module1.153 (HDMI0_HOTPLUG)
/CM5_HighSpeed/HDMI0_SCL: J6.15 (SCL), Module1.200 (HDMI0_SCL)
/CM5_HighSpeed/HDMI0_SDA: J6.16 (SDA), Module1.199 (HDMI0_SDA)
/CM5_HighSpeed/HDMI1_CEC: J7.13 (CEC), Module1.149 (HDMI1_CEC)
/CM5_HighSpeed/HDMI1_CK_N: J7.12 (CK-), Module1.166 (HDMI1_CLK_N)
/CM5_HighSpeed/HDMI1_CK_P: J7.10 (CK+), Module1.164 (HDMI1_CLK_P)
/CM5_HighSpeed/HDMI1_D0_N: J7.9 (D0-), Module1.160 (HDMI1_TX0_N)
/CM5_HighSpeed/HDMI1_D0_P: J7.7 (D0+), Module1.158 (HDMI1_TX0_P)
/CM5_HighSpeed/HDMI1_D1_N: J7.6 (D1-), Module1.154 (HDMI1_TX1_N)
/CM5_HighSpeed/HDMI1_D1_P: J7.4 (D1+), Module1.152 (HDMI1_TX1_P)
/CM5_HighSpeed/HDMI1_D2_N: J7.3 (D2-), Module1.148 (HDMI1_TX2_N)
/CM5_HighSpeed/HDMI1_D2_P: J7.1 (D2+), Module1.146 (HDMI1_TX2_P)
/CM5_HighSpeed/HDMI1_HOTPLUG: J7.19 (HPD/HEAC-), Module1.143 (HDMI1_HOTPLUG)
/CM5_HighSpeed/HDMI1_SCL: J7.15 (SCL), Module1.147 (HDMI1_SCL)
/CM5_HighSpeed/HDMI1_SDA: J7.16 (SDA), Module1.145 (HDMI1_SDA)
/CM5_HighSpeed/HDMI_5v: C8.1, J6.18 (+5V), J7.18 (+5V), U2.2 (OUT)
/CM5_HighSpeed/SCL0: J2.20, Module1.80 (SCL0)
/CM5_HighSpeed/SCL1: J3.20, J4.2, R7.2
/CM5_HighSpeed/SDA0: J2.21, Module1.82 (SDA0)
/CM5_HighSpeed/SDA1: J3.21, J4.4, R6.2
/CM5_HighSpeed/USB2_N: J20.2 (D-), Module1.103 (USB2_N)
/CM5_HighSpeed/USB2_P: J20.3 (D+), Module1.105 (USB2_P)
/CM5_HighSpeed/USB3-0-D_N: J5.A2 (D-), Module1.136 (USB3-0-D_N)
/CM5_HighSpeed/USB3-0-D_P: J5.A3 (D+), Module1.134 (USB3-0-D_P)
/CM5_HighSpeed/USB3-0-RX_N: J5.A6 (SSRX+), Module1.128 (USB3-0-RX_N)
/CM5_HighSpeed/USB3-0-RX_P: J5.A5 (SSRX-), Module1.130 (USB3-0-RX_P)
/CM5_HighSpeed/USB3-0-TX_N: J5.A9 (SSTX+), Module1.140 (USB3-0-TX_N)
/CM5_HighSpeed/USB3-0-TX_P: J5.A8 (SSTX-), Module1.142 (USB3-0-TX_P)
/CM5_HighSpeed/USB3-1-D_N: J5.B2 (D-), Module1.165 (USB3-1-D_N)
/CM5_HighSpeed/USB3-1-D_P: J5.B3 (D+), Module1.163 (USB3-1-D_P)
/CM5_HighSpeed/USB3-1-RX_N: J5.B6 (SSRX+), Module1.157 (USB3-1-RX_N)
/CM5_HighSpeed/USB3-1-RX_P: J5.B5 (SSRX-), Module1.159 (USB3-1-RX_P)
/CM5_HighSpeed/USB3-1-TX_N: J5.B9 (SSTX+), Module1.169 (USB3-1-TX_N)
/CM5_HighSpeed/USB3-1-TX_P: J5.B8 (SSTX-), Module1.171 (USB3-1-TX_P)
/CM5_HighSpeed/VBUS_EN: Module1.111 (VBUS_EN), U1.3 (EN)
GND: 5V_Fan1.2, C1.2, C2.2, C3.2, C4.2, C5.2, C6.2, C7.2, C8.2, C9.2, C19.2, C20.2, C22.1, C23.1, C24.1, C25.1, C26.1, D4.2 (A), J1.A1 (GND), J1.A12 (GND), J1.B1 (GND), J1.B12 (GND), J1.S1 (SHIELD), J2.1, J2.4, J2.7, J2.10, J2.13, J2.16, J2.19, J3.1, J3.4, J3.7, J3.10, J3.13, J3.16, J3.19, J5.10 (SHIELD), J5.A4 (GND), J5.A7 (DRAIN), J5.B4 (GND), J5.B7 (DRAIN), J6.2 (D2S), J6.5 (D1S), J6.8 (D0S), J6.11 (CKS), J6.17 (GND), J6.SH1 (SH), J6.SH2 (SH), J6.SH3 (SH), J6.SH4 (SH), J7.2 (D2S), J7.5 (D1S), J7.8 (D0S), J7.11 (CKS), J7.17 (GND), J7.SH1 (SH), J7.SH2 (SH), J7.SH3 (SH), J7.SH4 (SH), J8.1, J8.3, J8.5, J8.7, J8.9, J8.11, J8.13, J9.3, J10.2, J11.6, J11.9, J11.14, J11.20, J11.25, J11.30, J11.34, J11.39, J12.1, J14.1, J14.6, J15.2, J16.2, J17.2, J18.2, J20.4 (GND), J20.5 (Shield), J24.2, Module1.1 (GND), Module1.2 (GND), Module1.7 (GND), Module1.8 (GND), Module1.13 (GND), Module1.14 (GND), Module1.22 (GND), Module1.23 (GND), Module1.32 (GND), Module1.33 (GND), Module1.42 (GND), Module1.43 (GND), Module1.52 (GND), Module1.53 (GND), Module1.59 (GND), Module1.60 (GND), Module1.65 (GND), Module1.66 (GND), Module1.71 (GND), Module1.74 (GND), Module1.98 (GND), Module1.107 (GND), Module1.108 (GND), Module1.113 (GND), Module1.114 (GND), Module1.119 (GND), Module1.120 (GND), Module1.125 (GND), Module1.126 (GND), Module1.131 (GND), Module1.132 (GND), Module1.137 (GND), Module1.138 (GND), Module1.144 (GND), Module1.150 (GND), Module1.155 (GND), Module1.156 (GND), Module1.161 (GND), Module1.162 (GND), Module1.167 (GND), Module1.168 (GND), Module1.173 (GND), Module1.174 (GND), Module1.179 (GND), Module1.180 (GND), Module1.185 (GND), Module1.186 (GND), Module1.191 (GND), Module1.192 (GND), Module1.197 (GND), Module1.198 (GND), R1.1, R2.2, R3.2, R4.2, R25.1, R28.1, SPI_1.5, SPI_1.8, SPI_2.5, SPI_2.8, SW1.2, U1.2 (GND), U2.3 (GND), U3.3 (GND), U3.8 (GND), U4.3 (GND), U4.8 (GND), U5.19 (SHIELD), U5.20 (SHIELD), U8.7 (GND), U8.9 (EP), U9.1 (A)
unnamed: C9.1, U5.4 (CT), U5.5 (CT)
unnamed: C24.2, R26.1
unnamed: D1.1 (K), R9.1, TP3.1
unnamed: D2.1 (K), R13.1, TP4.1
unnamed: J1.A6 (D+), J1.B6 (D+)
unnamed: J1.A7 (D-), J1.B7 (D-)
unnamed: J3.17, R5.2
unnamed: J12.2, R10.2
unnamed: J14.5, JP1.2 (B)
unnamed: Module1.21 (LED_nACT), R9.2
unnamed: R4.1, U1.5 (ILIM)
unnamed: R15.1, U5.18 (LEDG_K)
unnamed: R14.1, U5.16 (LEDY_K)
unnamed: C21.1, U8.1 (BOOT)
unnamed: C22.2, R26.2, U8.6 (COMP)
unnamed: R27.1, R28.2, U8.5 (FB)
unnamed: R25.2, U8.4 (RT/CLK)
unnamed: C21.2, U8.8 (SW), U9.2 (K), U10.1
VBUS: C4.1, C5.1, C6.1, J5.A1 (VBUS), J5.B1 (VBUS), J20.1 (VBUS), U1.6 (OUT)

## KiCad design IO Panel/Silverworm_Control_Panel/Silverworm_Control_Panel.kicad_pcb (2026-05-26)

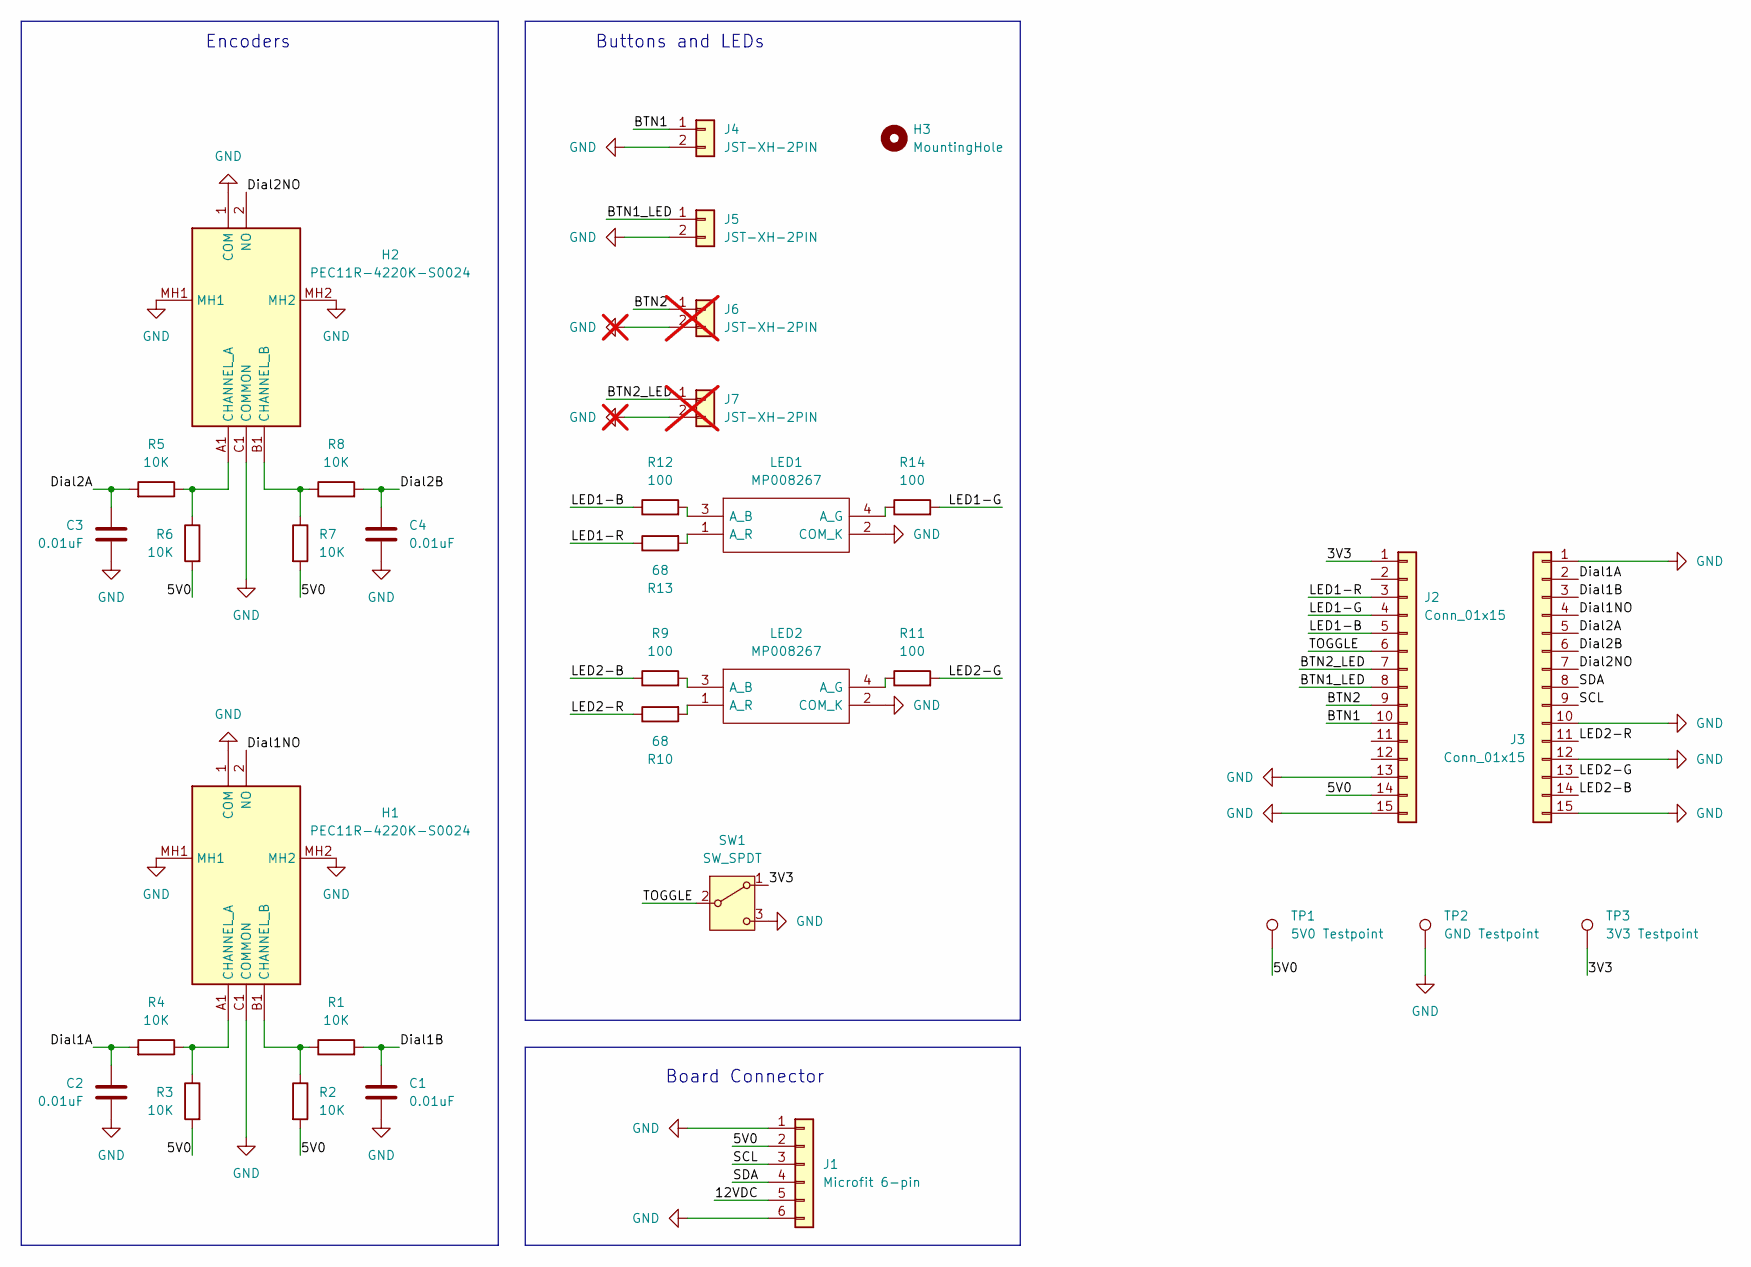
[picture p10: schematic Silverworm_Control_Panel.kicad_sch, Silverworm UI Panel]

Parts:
C1, C2, C3, C4: 0.01uF; C_0805_2012Metric_Pad1.18x1.45mm_HandSolder
H1, H2: PEC11R-4220K-S0024; PEC11R4220KS0024; Manufacturer_Part_Number PEC11R-4220K-S0024
H3: MountingHole; MountingHole_17mm_Pad_TopBottom
J1: Microfit 6-pin; Molex_Micro-Fit_3.0_43045-0621_2x03-1MP_P3.00mm_Horizontal; Manufacturer_Part_Number 430450621
J2, J3: Conn_01x15; PinSocket_1x15_P2.54mm_Vertical; Manufacturer_Part_Number M20-7821546
J4, J5: JST-XH-2PIN; JST_PH_B2B-PH-K_1x02_P2.00mm_Vertical; Manufacturer_Part_Number B2B-XH-A(LF)(SN)
J6, J7: JST-XH-2PIN; Manufacturer_Part_Number B2B-XH-A(LF)(SN); not fitted
LED1, LED2: MP008267; Manufacturer_Part_Number MP008267
R1, R2, R3, R4, R5, R6, R7, R8: 10K; R_0805_2012Metric_Pad1.20x1.40mm_HandSolder
R9, R11, R12, R14: 100; R_0805_2012Metric_Pad1.20x1.40mm_HandSolder
R10, R13: 68; R_0805_2012Metric_Pad1.20x1.40mm_HandSolder
SW1: SW_SPDT; HDRV3W51P470X254_1X3_813X508X2100P; Manufacturer_Part_Number 200MSP1T1B2M2QE
TP1: 5V0 Testpoint; TestPoint_THTPad_D2.5mm_Drill1.2mm
TP2: GND Testpoint; TestPoint_Pad_D3.0mm
TP3: 3V3 Testpoint; TestPoint_THTPad_D2.5mm_Drill1.2mm

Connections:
/3V3: J2.1, SW1.1 (A), TP3.1
/5V0: J1.2, J2.14, R2.2, R3.2, R6.2, R7.2, TP1.1
/12VDC: J1.5
/BTN1: J2.10, J4.1
/BTN1_LED: J2.8, J5.1
/BTN2: J2.9, J6.1
/BTN2_LED: J2.7, J7.1
/Dial1A: C2.1, J3.2, R4.2
/Dial1B: C1.1, J3.3, R1.2
/Dial1NO: H1.2 (NO), J3.4
/Dial2A: C3.1, J3.5, R5.2
/Dial2B: C4.1, J3.6, R8.2
/Dial2NO: H2.2 (NO), J3.7
/LED1-B: J2.5, R12.1
/LED1-G: J2.4, R14.2
/LED1-R: J2.3, R13.1
/LED2-B: J3.14, R9.1
/LED2-G: J3.13, R11.2
/LED2-R: J3.11, R10.1
/SCL: J1.3, J3.9
/SDA: J1.4, J3.8
/TOGGLE: J2.6, SW1.2 (B)
GND: C1.2, C2.2, C3.2, C4.2, H1.1 (COM), H1.C1 (COMMON), H1.MH1, H1.MH2, H2.1 (COM), H2.C1 (COMMON), H2.MH1, H2.MH2, J1.1, J1.6, J2.13, J2.15, J3.1, J3.10, J3.12, J3.15, J4.2, J5.2, J6.2, J7.2, LED1.2 (COM_K), LED2.2 (COM_K), SW1.3 (C), TP2.1
unnamed: H1.A1 (CHANNEL_A), R3.1, R4.1
unnamed: H1.B1 (CHANNEL_B), R1.1, R2.1
unnamed: H2.A1 (CHANNEL_A), R5.1, R6.1
unnamed: H2.B1 (CHANNEL_B), R7.1, R8.1
unnamed: LED1.3 (A_B), R12.2
unnamed: LED1.4 (A_G), R14.1
unnamed: LED1.1 (A_R), R13.2
unnamed: LED2.3 (A_B), R9.2
unnamed: LED2.4 (A_G), R11.1
unnamed: LED2.1 (A_R), R10.2

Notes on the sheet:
Buttons and LEDs
Encoders
Board Connector

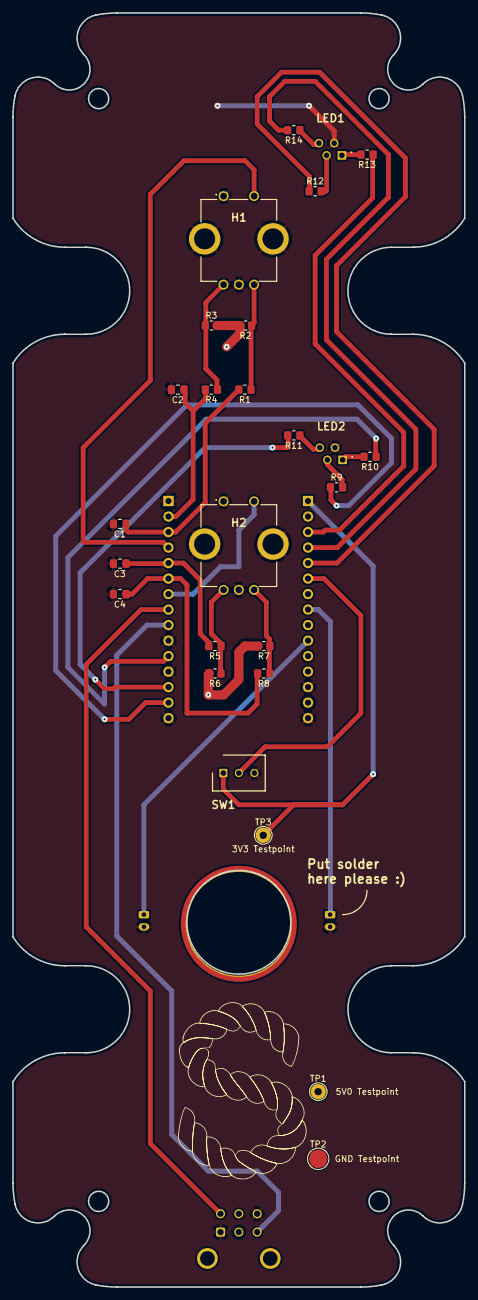
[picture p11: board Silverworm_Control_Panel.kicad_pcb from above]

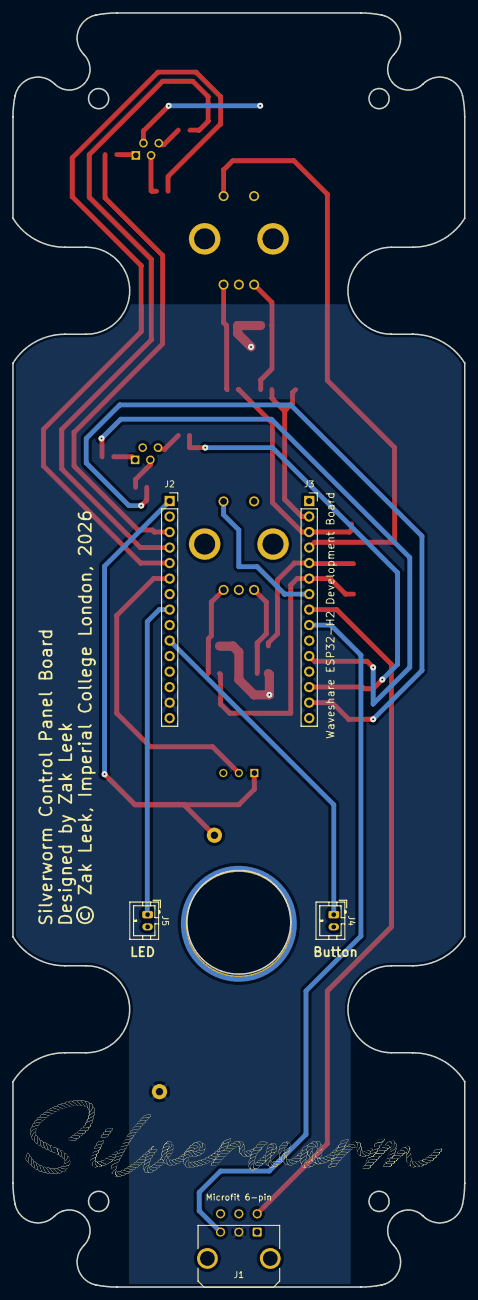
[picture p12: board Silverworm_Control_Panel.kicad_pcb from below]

Board: 2 copper layers, 74.0 x 208.7 mm, 32 parts (5 on the bottom side), 30 nets.

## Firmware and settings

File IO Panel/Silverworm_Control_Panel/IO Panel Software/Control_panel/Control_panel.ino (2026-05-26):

#include <Wire.h>

// Pin Definitions
// RGB LED 1
const int LED1_R = 0;
const int LED1_G = 1;
const int LED1_B = 2;

// RGB LED 2
const int LED2_R = 9;
const int LED2_G = 27;
const int LED2_B = 26;

// Buttons and Switches
const int BTN1 = 5;
const int BTN1_LED = 14;
const int TOGGLE = 3;

// Encoders
const int DIAL1A = 24;
const int DIAL1B = 23;
const int DIAL1_BTN = 10;

const int DIAL2A = 11;
const int DIAL2B = 25;
const int DIAL2_BTN = 12;

// I2C Configuration
const uint8_t I2C_SLAVE_ADDR = 0x55;
const int I2C_SDA = 8;
const int I2C_SCL = 22;

// Debounce constants
const unsigned long DEBOUNCE_MS = 20;
const unsigned long RAINBOW_TIMEOUT_MS = 300; // Return to normal colour after 300ms of inactivity

// State variables
unsigned long lastBtnPress = 0;
bool lastBtnState = HIGH;

unsigned long lastToggleRead = 0;
bool lastToggleState = HIGH;

int encoderMode[2] = {0, 0}; // 0=large/green, 1=medium/yellow, 2=small/red
unsigned long lastEncoderBtnPress[2] = {0, 0};
bool lastEncoderBtnState[2] = {HIGH, HIGH};

unsigned long lastEncoderRotation[2] = {0, 0}; // Track last rotation time for rainbow effect
int rainbowIndex[2] = {0, 0}; // Current position in rainbow cycle

volatile int lastEncoderA[2] = {HIGH, HIGH};
volatile int lastEncoderB[2] = {HIGH, HIGH};

bool powerLEDStatus = false;

// I2C command queue
char commandBuffer[32] = "";
int commandBufferIndex = 0;

// Colour definitions (RGB values 0-255)
const uint8_t colourBig[3] = {0, 255, 0};       // Large detent
const uint8_t colourMedium[3] = {255, 200, 0};  // Medium detent
const uint8_t colourSmall[3] = {255, 0, 0};     // Small detent
const uint8_t colourOff[3] = {0, 0, 0};

// Rainbow colours for encoder rotation animation (24 colours = 1 per dial step for smooth animation)
const uint8_t rainbowColours[24][3] = {
  {255, 0, 0},      // Red
  {255, 32, 0},     // Red-Orange
  {255, 64, 0},     // Orange
  {255, 96, 0},     // Orange
  {255, 128, 0},    // Orange-Yellow
  {255, 160, 0},    // Yellow-Orange
  {255, 192, 0},    // Yellow
  {255, 224, 0},    // Yellow
  {224, 255, 0},    // Yellow-Green
  {160, 255, 0},    // Green-Yellow
  {96, 255, 0},     // Green
  {32, 255, 0},     // Green
  {0, 255, 32},     // Green-Cyan
  {0, 255, 96},     // Cyan-Green
  {0, 255, 160},    // Cyan
  {0, 255, 224},    // Cyan
  {0, 192, 255},    // Cyan-Blue
  {0, 128, 255},    // Blue-Cyan
  {0, 64, 255},     // Blue
  {0, 32, 255},     // Blue
  {64, 0, 255},     // Blue-Purple
  {128, 0, 255},    // Purple
  {192, 0, 255},    // Purple-Red
  {255, 0, 192}     // Red-Purple
};
const int RAINBOW_COLOURS_COUNT = 24;

void setup() {
  Serial.begin(115200);
  delay(1000);

  // Initialize pins
  pinMode(BTN1, INPUT_PULLUP);
  pinMode(BTN1_LED, OUTPUT);
  digitalWrite(BTN1_LED, LOW);

  pinMode(TOGGLE, INPUT_PULLUP);

  pinMode(DIAL1A, INPUT);
  pinMode(DIAL1B, INPUT);
  pinMode(DIAL1_BTN, INPUT_PULLUP);

  pinMode(DIAL2A, INPUT);
  pinMode(DIAL2B, INPUT);
  pinMode(DIAL2_BTN, INPUT_PULLUP);

  // RGB LEDs
  pinMode(LED1_R, OUTPUT);
  pinMode(LED1_G, OUTPUT);
  pinMode(LED1_B, OUTPUT);

  pinMode(LED2_R, OUTPUT);
  pinMode(LED2_G, OUTPUT);
  pinMode(LED2_B, OUTPUT);

  // Set initial LED colours
  setRGBLED(1, colourBig);
  setRGBLED(2, colourBig);

  // Initialize I2C slave
  Wire.begin((uint8_t)I2C_SLAVE_ADDR, I2C_SDA, I2C_SCL, 400000);
  Wire.onReceive(onI2CReceive);
  Wire.onRequest(onI2CRequest);

  Serial.println("ESP32-H2 IO Panel initialized");
}

void loop() {
  unsigned long now = millis();

  handlePowerButton();
  handleToggleSwitch();
  handleEncoder(0, DIAL1A, DIAL1B, DIAL1_BTN);
  handleEncoder(1, DIAL2A, DIAL2B, DIAL2_BTN);

  // Check if encoders should return to normal colour mode
  for (int i = 0; i < 2; i++) {
    if ((now - lastEncoderRotation[i]) > RAINBOW_TIMEOUT_MS) {
      updateEncoderLED(i); // Return to normal colour
    }
  }

  delay(5);
}

// Handle power button press
void handlePowerButton() {
  bool currentState = digitalRead(BTN1);
  unsigned long now = millis();

  if (currentState == LOW && lastBtnState == HIGH) {
    if (now - lastBtnPress > DEBOUNCE_MS) {
      sendI2CCommand("TP");
      lastBtnPress = now;
    }
  }

  lastBtnState = currentState;
}

// Handle toggle switch
void handleToggleSwitch() {
  bool currentState = digitalRead(TOGGLE);
  unsigned long now = millis();

  if (currentState != lastToggleState) {
    if (now - lastToggleRead > DEBOUNCE_MS) {
      if (currentState == LOW) {
        sendI2CCommand("AS0"); // Manual mode
      } else {
        sendI2CCommand("AS1"); // Automatic mode
      }
      lastToggleState = currentState;
      lastToggleRead = now;
    }
  }
}

// Handle encoder rotation and button
void handleEncoder(int encoderIdx, int pinA, int pinB, int pinBtn) {
  // Handle encoder button press
  bool btnState = digitalRead(pinBtn);
  unsigned long now = millis();

  if (btnState == LOW && lastEncoderBtnState[encoderIdx] == HIGH) {
    if (now - lastEncoderBtnPress[encoderIdx] > DEBOUNCE_MS) {
      // Cycle through modes
      encoderMode[encoderIdx] = (encoderMode[encoderIdx] + 1) % 3;
      updateEncoderLED(encoderIdx);
      lastEncoderBtnPress[encoderIdx] = now;
    }
  }

  lastEncoderBtnState[encoderIdx] = btnState;

  // Handle encoder rotation using quadrature decoding for Bourns PEC11R
  int currentA = digitalRead(pinA);
  int currentB = digitalRead(pinB);
  int lastA = lastEncoderA[encoderIdx];
  int lastB = lastEncoderB[encoderIdx];

  // Full quadrature state change detection
  if (currentA != lastA || currentB != lastB) {
    // Quadrature lookup table: determine if clockwise (1) or counter-clockwise (-1)
    // States: 00, 01, 10, 11 (4 possible states)
    // Clockwise sequence: 11->10->00->01->11
    // Counter-clockwise: 11->01->00->10->11

    int oldState = (lastA << 1) | lastB;      // Previous state
    int newState = (currentA << 1) | currentB; // Current state

    // Simple quadrature table approach
    // Only trigger on certain transitions to avoid jitter
    if (oldState == 3 && newState == 2) {  // 11->10: clockwise step 1
      sendEncoderCommand(encoderIdx, 1);
    } else if (oldState == 2 && newState == 0) {  // 10->00: clockwise step 2
      sendEncoderCommand(encoderIdx, 1);
    } else if (oldState == 0 && newState == 1) {  // 00->01: clockwise step 3
      sendEncoderCommand(encoderIdx, 1);
    } else if (oldState == 1 && newState == 3) {  // 01->11: clockwise step 4
      sendEncoderCommand(encoderIdx, 1);
    }
    // Counter-clockwise transitions
    else if (oldState == 3 && newState == 1) {  // 11->01: counter-clockwise step 1
      sendEncoderCommand(encoderIdx, -1);
    } else if (oldState == 1 && newState == 0) {  // 01->00: counter-clockwise step 2
      sendEncoderCommand(encoderIdx, -1);
    } else if (oldState == 0 && newState == 2) {  // 00->10: counter-clockwise step 3
      sendEncoderCommand(encoderIdx, -1);
    } else if (oldState == 2 && newState == 3) {  // 10->11: counter-clockwise step 4
      sendEncoderCommand(encoderIdx, -1);
    }

    lastEncoderA[encoderIdx] = currentA;
    lastEncoderB[encoderIdx] = currentB;
  }
}

// Send encoder command with proper increment and rainbow animation
void sendEncoderCommand(int encoderIdx, int direction) {
  int increment = getIncrementForMode(encoderMode[encoderIdx]);
  char cmd[16];

  if (direction > 0) {
    sprintf(cmd, "D%d+%d", encoderIdx + 1, increment);
  } else {
    sprintf(cmd, "D%d-%d", encoderIdx + 1, increment);
  }

  sendI2CCommand(cmd);

  // Update rainbow animation
  lastEncoderRotation[encoderIdx] = millis();
  rainbowIndex[encoderIdx] = (rainbowIndex[encoderIdx] + 1) % RAINBOW_COLOURS_COUNT;
  setRGBLED(encoderIdx + 1, rainbowColours[rainbowIndex[encoderIdx]]);
}

// Get increment value based on encoder mode
int getIncrementForMode(int mode) {
  switch(mode) {
    case 0: return 3;  // Large detent
    case 1: return 2;  // Medium detent
    case 2: return 1;  // Small detent
    default: return 1;
  }
}

// Update encoder RGB LED colour based on mode
void updateEncoderLED(int encoderIdx) {
  const uint8_t *colour;
  switch(encoderMode[encoderIdx]) {
    case 0:
      colour = colourBig;
      break;
    case 1:
      colour = colourMedium;
      break;
    case 2:
      colour = colourSmall;
      break;
    default:
      colour = colourOff;
  }
  setRGBLED(encoderIdx + 1, colour);
}

// Set RGB LED color
void setRGBLED(int ledIdx, const uint8_t color[3]) {
  if (ledIdx == 1) {
    analogWrite(LED1_R, color[0]);
    analogWrite(LED1_G, color[1]);
    analogWrite(LED1_B, color[2]);
  } else if (ledIdx == 2) {
    analogWrite(LED2_R, color[0]);
    analogWrite(LED2_G, color[1]);
    analogWrite(LED2_B, color[2]);
  }
}

// I2C receive handler - receive status from Raspberry Pi
void onI2CReceive(int len) {
  if (len >= 2) {
    char buffer[len + 1];
    int i = 0;
    while (Wire.available()) {
      buffer[i++] = Wire.read();
    }
    buffer[i] = '\0';

    // Parse ON/OFF status
    if (strncmp(buffer, "ON", 2) == 0) {
      digitalWrite(BTN1_LED, HIGH);
      powerLEDStatus = true;
    } else if (strncmp(buffer, "OFF", 3) == 0) {
      digitalWrite(BTN1_LED, LOW);
      powerLEDStatus = false;
    }
  }
}

// I2C request handler - send command to Raspberry Pi
void onI2CRequest() {
  if (commandBufferIndex > 0) {
    Wire.write((uint8_t *)commandBuffer, commandBufferIndex);
    commandBufferIndex = 0;
    memset(commandBuffer, 0, sizeof(commandBuffer));
  } else {
    Wire.write(0); // Send null byte if no command
  }
}

// Queue I2C command to be sent to Raspberry Pi when requested
void sendI2CCommand(const char *cmd) {
  memset(commandBuffer, 0, sizeof(commandBuffer));
  strncpy(commandBuffer, cmd, sizeof(commandBuffer) - 2);
  commandBufferIndex = strlen(commandBuffer) + 1; // Include null terminator

  Serial.print("Queued I2C command: ");
  Serial.println(cmd);
}

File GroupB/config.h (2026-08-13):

#pragma once

// =============================================================================
// Pin assignments — Arduino Uno R2 (ATmega328P)
// =============================================================================

// --- FSK40J linear stage (NEMA 23 via DM423T) ---
#define LINEAR_STEP_PIN         2   // D2
#define LINEAR_DIR_PIN          3   // D3
#define LINEAR_ENABLE_PIN       4   // D4
// DM423T PUL-/DIR-/ENA- → Nucleo GND

// --- Second-shaft encoder #2 (IHC3808 on roller / line) ---
#define ENC2_A_PIN              5   // D5
#define ENC2_B_PIN              6   // D6
#define ENC2_Z_PIN              7   // D7 — index; set -1 if not wired
#define ENC2_CPR                8000 // 2000 PPR × 4 (quadrature); verify datasheet

// --- oDrive S1 UART (42BSA62; encoder #1 on oDrive ENC0) ---
#define ODRIVE_UART_RX_PIN      8   // D8  ← oDrive TX
#define ODRIVE_UART_TX_PIN      9   // D9  → oDrive RX
#define ODRIVE_BAUD             19200
#define ODRIVE_AXIS             0

// --- SPI slave to Raspberry Pi (hardware SPI pins on Uno) ---
// D10 SS (NSS/CS), D11 MOSI, D12 MISO, D13 SCK

// Limit switches (optional)
#define LINEAR_LIMIT_MIN_PIN      A0
#define LINEAR_LIMIT_MAX_PIN      A1

// =============================================================================
// Linear stage (FSK40J + NEMA 23)
// =============================================================================

#define LINEAR_FULL_STEPS_PER_REV  200
#define LINEAR_SCREW_LEAD_MM       10.0f
#define LINEAR_MICROSTEPS          16
#define LINEAR_ENABLE_ACTIVE_LOW   true

#define LINEAR_STROKE_MM_DEFAULT   250.0f
#define LINEAR_MAX_SPEED_MM_S      150.0f
#define LINEAR_MAX_ACCEL_MM_S2     800.0f

// =============================================================================
// Collecting spool BLDC (42BSA62 via oDrive S1)
// =============================================================================

#define BLDC_RATED_RPM             10
#define ODRIVE_FEEDBACK_INTERVAL_MS  50
#define SPI_SPEED_RAMP_RPM_S       500

// =============================================================================
// Second-shaft encoder telemetry
// =============================================================================

#define ENC2_RPM_FILTER_MS         100
#define ENC2_PLOT_MS               50   // Serial Plotter sample interval (ms)

// =============================================================================
// SPI / bench
// =============================================================================

#define SPI_TEST_LED_PIN           LED_BUILTIN
#define SPI_TEST_PULSE_MS          500

// =============================================================================
// Feature flags
// =============================================================================

// Set to 1 to compile BldcMotor (ODriveUART + SoftwareSerial) and LinearStage.
// When 1, SoftwareSerial owns PCINT2_vect; ShaftEncoder's PCINT2 ISR is
// compiled out (see ShaftEncoder.cpp) so the encoder on D5–D7 is inactive.
#define MOTORS_ENABLED             1

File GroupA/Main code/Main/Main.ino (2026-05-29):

#include <Arduino.h>
#include <SPI.h>
#include "Interrupts.h"
#include <QuickPID.h>
#include "motor.h"
#include <avr/interrupt.h>

#define INA 4
#define INB 2
#define PWM 3
#define HALL 5

// Nano Every hardware SPI ALT2 pins:
// CS/SS = D8
// MOSI  = D11
// MISO  = D12
// SCK   = D13
#define SPI_SS_PIN 8
#define SPI_MOSI_PIN 11
#define SPI_MISO_PIN 12
#define SPI_SCK_PIN 13



// === SPI slave configuration (Nano Every / ATmega4809) ===
// Raspberry Pi SPI modes:
// - Mode 0: CPOL=0, CPHA=0
// - Mode 1: CPOL=0, CPHA=1
// - Mode 2: CPOL=1, CPHA=0
// - Mode 3: CPOL=1, CPHA=1
//
// Change this if the Pi reads garbage / shifted bytes.
constexpr uint8_t SPI_DATA_MODE = 0; // 0..3

volatile byte receivedBuffer[3];
volatile byte completedCommand[3];
volatile byte bufferIndex = 0;
volatile byte expectedCommandLength = 0;
volatile bool newCommand = false;

volatile byte replyBuffer[3];
volatile byte replyLength = 0;
volatile byte replyIndex = 0;

Motor motor(INA, INB, PWM);

float omega_ref = 0;
float currentSpeed = 0.0;
float targetPWM = 18;

float omega_target = 0;
float rampRate = 0.2;

QuickPID speedPID(&currentSpeed, &targetPWM, &omega_ref,
                  0.35, 0.15
                  , 0.0, QuickPID::Action::direct);


bool spiIdle() {
  return bufferIndex == 0 && replyLength == 0 && replyIndex == 0;
}

bool setReply(byte a, byte b = 0, byte c = 0, byte length = 1) {
  bool ok = false;

  noInterrupts();
  if (spiIdle()) {
    replyBuffer[0] = a;
    replyBuffer[1] = b;
    replyBuffer[2] = c;
    replyLength = length;
    replyIndex = 0;
    ok = true;
  }
  interrupts();

  return ok;
}

static inline uint8_t spiModeToCtrlb(uint8_t mode) {
  switch (mode & 0x03) {
    case 0: return SPI_MODE_0_gc;
    case 1: return SPI_MODE_1_gc;
    case 2: return SPI_MODE_2_gc;
    default: return SPI_MODE_3_gc;
  }
}

ISR(SPI0_INT_vect) {
  byte c = SPI0.DATA;

  if (bufferIndex < sizeof(receivedBuffer)) {
    receivedBuffer[bufferIndex++] = c;
  }

  if (bufferIndex == 1) {
    if (c == 0x01 || c == 0x03) {
      expectedCommandLength = 3;
    } 
    else if (c == 0x02) {
      expectedCommandLength = 2;
    } 
    else if (c == 0x04|| c == 0x05) {
      expectedCommandLength = 1;
    } 
    else {
      bufferIndex = 0;
      expectedCommandLength = 0;
      SPI0.DATA = 0;
      SPI0.INTFLAGS = SPI_IF_bm;
      return;
    }
  }

  if (expectedCommandLength > 0 && bufferIndex >= expectedCommandLength) {
    for (byte i = 0; i < 3; i++) {
      completedCommand[i] = i < expectedCommandLength ? receivedBuffer[i] : 0;
    }

    bufferIndex = 0;
    expectedCommandLength = 0;
    newCommand = true;
  }

  if (replyIndex < replyLength) {
    SPI0.DATA = replyBuffer[replyIndex++];
  } else {
    SPI0.DATA = 0;
    replyLength = 0;
    replyIndex = 0;
  }

  SPI0.INTFLAGS = SPI_IF_bm;
}

void setup() {
  // Serial.begin(9600);

  pinMode(HALL, INPUT_PULLUP);
  attachInterrupt(digitalPinToInterrupt(HALL), hallISR, FALLING);

  speedPID.SetOutputLimits(18, 255);
  speedPID.SetSampleTimeUs(50000);
  speedPID.SetMode(QuickPID::Control::automatic);

  PORTMUX.TWISPIROUTEA = PORTMUX_SPI0_ALT2_gc;

  pinMode(SPI_SS_PIN, INPUT_PULLUP);
  pinMode(SPI_MOSI_PIN, INPUT);
  pinMode(SPI_MISO_PIN, OUTPUT);
  pinMode(SPI_SCK_PIN, INPUT);

  SPI0.CTRLA = 0;
  SPI0.CTRLB = spiModeToCtrlb(SPI_DATA_MODE);
  SPI0.INTFLAGS = SPI_IF_bm;
  SPI0.INTCTRL = SPI_IE_bm;
  SPI0.DATA = 0;

  SPI0.CTRLA = SPI_ENABLE_bm;

  interrupts();






}

// Called when SS goes HIGH (end of SPI transaction). Resets framing state
// so the next transaction is treated as a fresh command.
void onSSDeassert() {
    bufferIndex = 0;
    expectedCommandLength = 0;
}

void loop() {
  byte command[3] = {0, 0, 0};

  if (newCommand) {
    noInterrupts();
    for (byte i = 0; i < 3; i++) {
      command[i] = completedCommand[i];
    }
    newCommand = false;
    interrupts();

    byte prefix = command[0];
    byte second = command[1];

    switch (prefix) {
      case 0x01: {
        int speed_rpm = command[1] | (command[2] << 8);
        float speed_rad = speed_rpm * (2.0 * 3.14156 / 60.0);
        omega_target = speed_rad;
        rampRate = 0.2;
        setReply(0x03, 0x01, 0, 2);
        break;
      }

      case 0x02: {
            motor.setSpeed(0);
            omega_target = 0;
            omega_ref = 0;
            targetPWM = 0;
            speedPID.Reset();
            setReply(0x03, 0x02, 0, 2);

            break;
      }
      //   switch (second) {
      //     case '1': {
      //       omega_target = 0;
      //       rampRate = 0.2;
      //       setReply('3', '2', 0, 2);
      //       break;
      //     }

      //     case '2': {
      //       motor.setSpeed(0);
      //       omega_target = 0;
      //       omega_ref = 0;
      //       targetPWM = 0;
      //       speedPID.Reset();
      //       setReply('3', '2', 0, 2);
      //       break;
      //     }

      //     case '3': {
      //       motor.setSpeed(0);
      //       omega_target = 0;
      //       omega_ref = 0;
      //       targetPWM = 0;
      //       speedPID.Reset();
      //       setReply('3', '2', 0, 2);
      //       break;
      //     }

      //     default: {
      //       setReply('2', '1', 0, 2);
      //       break;
      //     }
      //   }
      //   break;
      // }

      case 0x03: {
        int speed_rpm = command[1] | (command[2] << 8);
        float speed_rad = speed_rpm * (2.0 * 3.14156 / 60.0);
        omega_target = speed_rad;
        rampRate = 20;
        setReply(0x03, 0x03, 0, 2);
        break;
      }

      case 0x04: {
        // Serial.println("test command received");
        setReply(0x03, 0x04, 0x00, 2);
        break;
      }

      case 0x05: {
        unsigned long now = micros();

        int speed;

        if (lastPulseTime > 0 && (now - lastPulseTime) > 2000000UL){
          speed = -5;
        } else {
          speed = (int)(currentSpeed * 60.0 / (2.0 * 3.14156));

        }
        
        setReply(speed & 0xFF,
         (speed >> 8) & 0xFF,
         0,
         2);
        
        break;
      }

      default: {
        setReply(0x02, 0x01, 0x00, 2);
        break;
      }
    }
  }

  noInterrupts();
  unsigned long last = lastPulseTime;
  currentSpeed = omega;
  interrupts();

  if (
      (last > 0 && (micros() - last) > 2000000UL)
    ) {

      currentSpeed = 0;

      noInterrupts();
      omega = 0;
      interrupts();
  }

  if (omega_ref < omega_target) {
    omega_ref += rampRate;
    if (omega_ref > omega_target) omega_ref = omega_target;
  }

  if (omega_ref > omega_target) {
    omega_ref -= rampRate;
    if (omega_ref < omega_target) omega_ref = omega_target;
  }

  speedPID.Compute();
  targetPWM = constrain(targetPWM, 0, 225);
  motor.setSpeed((int)targetPWM);

  // Serial.print(currentSpeed * 60.0 / (2.0 * 3.14156));
  // Serial.print(",");
  // Serial.print(omega_target * 60.0 / (2.0 * 3.14156));
  // Serial.print(",");
  // Serial.println(targetPWM);
}

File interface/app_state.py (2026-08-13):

"""
Central application state.

Single source of truth for:
  - mode (AUTO / MANUAL)
  - machine_on (machine power state)
  - wrap_speed_rpm  (dial 1 / D1 — wrap motor)
  - feed_speed_mms  (dial 2 / D2 — feed motor)

Receives events from two places:
  - PUI (Physical UI, via PUIListener signals or direct apply_* calls)
  - GUI (via gui_set_* methods)

PUI precedence rule
-------------------
PUI is the source of truth for `mode`. We track the last-known state of
the physical auto/manual switch in `_pui_in_manual` (set by AS0/AS1).

  - PUI mode-switch events always win: AS0/AS1 immediately change the mode.
  - GUI → MANUAL is always allowed (covers low-confidence auto-trigger
    and operator overrides "into" manual).
  - GUI → AUTO is REJECTED while `_pui_in_manual` is True. The operator
    must flip the physical switch to AUTO first. A `mode_change_blocked`
    signal carries the reason so the UI can warn the user.

Speeds and machine_on follow simple "last write wins" — only mode has
a hard PUI lock, because manual mode gates access to the dial-driven
speed inputs.

Routing to motors
-----------------
AppState holds two MotorControllers (wrap, feed) and forwards:
  - machine_on transitions   → start(speed) or stop(RAMP_DOWN)
  - speed changes while on   → set_speed(units)
Speed changes while the machine is off do not transmit; they update
state only and will be applied on the next start.

Tests can construct AppState without motors (pass None) — speed/power
changes still update state and emit signals, just without any I/O.
"""

from __future__ import annotations

from enum import Enum
from typing import Optional

from PyQt6.QtCore import QObject, pyqtSignal

from comms.pui import DialChange, ModeSwitch, PUIMode, DetentSize
from comms.motor_spi import MotorController, StopType, SPEED_MAX
from config import (
    AppConfig,
    WRAP_SPEED_MIN_RPM, WRAP_SPEED_MAX_RPM,
    FEED_SPEED_MIN_MMS, FEED_SPEED_MAX_MMS,
)


class Mode(Enum):
    AUTO = "auto"
    MANUAL = "manual"


# Manual-speed bounds live in config.py (single source of truth). They are
# imported above and used as application-side clamps to prevent obvious
# nonsense from PUI dial accumulation; the motor enforces real limits.


# Physical → SPI integer scaling. Confirm with Arduino firmware once
# the units they expect are pinned down.
WRAP_RPM_UNITS_PER = 1         # 1 unit = 1 RPM (Arduino expects raw RPM)
FEED_MMS_UNITS_PER = 1         # 1 unit = 1 mm/s (Arduino expects raw mm/s)


def _scale_to_units(value: float, units_per: int) -> int:
    return max(0, min(SPEED_MAX, int(value * units_per + 0.5)))


def rpm_to_units(rpm: float) -> int:
    return _scale_to_units(rpm, WRAP_RPM_UNITS_PER)


def mms_to_units(mms: float) -> int:
    return _scale_to_units(mms, FEED_MMS_UNITS_PER)


class AppState(QObject):
    """Central mutable state + signal hub + motor routing."""

    mode_changed = pyqtSignal(object)            # Mode
    machine_power_changed = pyqtSignal(bool)
    wrap_speed_changed = pyqtSignal(float)       # rpm
    feed_speed_changed = pyqtSignal(float)       # mm/s
    motor_error = pyqtSignal(str)                # SPI / hardware error message
    mode_change_blocked = pyqtSignal(str)        # human-readable reject ion reason

    def __init__(
        self,
        config: AppConfig,
        wrap_motor: Optional[MotorController] = None,
        feed_motor: Optional[MotorController] = None,
        parent=None,
    ):
        super().__init__(parent)
        self._config = config
        self._wrap_motor = wrap_motor
        self._feed_motor = feed_motor

        self._mode: Mode = Mode.AUTO
        self._machine_on: bool = False
        self._wrap_speed_rpm: float = 0.0
        self._feed_speed_mms: float = 0.0
        # Last-known position of the PUI auto/manual switch. While True,
        # GUI requests to leave manual mode are rejected. Edge-triggered
        # from AS0/AS1; if the PUI boots in MANUAL but never sends AS0,
        # this stays False (a hardware-sync limitation, not solvable here).
        self._pui_in_manual: bool = False

    # ----- read-only accessors ------------------------------------------

    @property
    def mode(self) -> Mode:
        return self._mode

    @property
    def machine_on(self) -> bool:
        return self._machine_on

    @property
    def wrap_speed_rpm(self) -> float:
        return self._wrap_speed_rpm

    @property
    def feed_speed_mms(self) -> float:
        return self._feed_speed_mms

    @property
    def config(self) -> AppConfig:
        return self._config

    # ----- PUI event handlers -------------------------------------------

    def apply_dial_change(self, change: DialChange) -> None:
        """
        Apply a dial detent event. The dial sends an *increment*, not an
        absolute value — we look up (dial, size) in DetentConfig and add.

        Dial events only mutate speed in MANUAL mode. In AUTO the vision
        pipeline owns speed, so dial events are ignored. (Confirm with
        PUI firmware author whether dial events should also be ignored
        on the panel side while in auto — for now we just drop them.)
        """
        if self._mode != Mode.MANUAL:
            return

        delta = self._increment_for(change)
        if change.dial == 1:
            self._set_wrap_speed(self._wrap_speed_rpm + delta)
        elif change.dial == 2:
            self._set_feed_speed(self._feed_speed_mms + delta)

    def apply_mode_switch(self, switch: ModeSwitch) -> None:
        new_mode = Mode.MANUAL if switch.mode == PUIMode.MANUAL else Mode.AUTO
        self._pui_in_manual = (new_mode == Mode.MANUAL)
        self._set_mode(new_mode)

    def apply_power_toggle(self) -> None:
        self._set_machine_on(not self._machine_on)

    # ----- GUI mutators (same setters — PUI just wins by overwriting) ---

    def gui_set_mode(self, mode: Mode) -> None:
        # PUI lock: while the physical switch is in MANUAL, the GUI cannot
        # leave manual mode. GUI → MANUAL is always allowed (covers low-
        # confidence auto-trigger).
        if mode == Mode.AUTO and self._pui_in_manual:
            self.mode_change_blocked.emit(
                "PUI is in MANUAL — flip the panel switch to leave manual mode"
            )
            return
        self._set_mode(mode)

    def gui_set_wrap_speed(self, rpm: float) -> None:
        self._set_wrap_speed(rpm)

    def gui_set_feed_speed(self, mms: float) -> None:
        self._set_feed_speed(mms)

    def gui_set_machine_on(self, on: bool) -> None:
        self._set_machine_on(on)

    # ----- internal setters ---------------------------------------------

    def _set_mode(self, mode: Mode) -> None:
        if self._mode == mode:
            return
        self._mode = mode
        self.mode_changed.emit(mode)
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

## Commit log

2026-01-02 Added KiCAD Project for Motherboard
    KiCAD project is copied from the RPi template, requires edits
    [CM5IO.kicad_pcb, CM5IO.kicad_sch, CM5_GPIO.kicad_sch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]
2026-01-11 Created README for SPI Setup on Raspberry Pi
2026-01-27 SPI Comms
2026-01-27 UI Panel Schematics
    [Silverworm_Control_Panel.kicad_pcb, Silverworm_Control_Panel.kicad_sch]
2026-01-27 Motherboard schematics edits
    [CM5IO.kicad_pcb, CM5IO.kicad_sch, CM5_GPIO.kicad_sch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]
2026-01-29 Imported PCB outline and layout
    Still need to finalise small component placement and routing.
    [Silverworm_Control_Panel.kicad_pcb, Silverworm_Control_Panel.kicad_sch, Silverworm_Control_Panel.step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]
2026-02-03 Added footprints and board connectors
    [CM5IO.kicad_pcb, CM5IO.kicad_sch, CM5IO_BOM_v1.csv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]
2026-02-03 Added 3d molex connector to UI panel
    [Silverworm_Control_Panel.kicad_pcb]
2026-02-05 Layout and IO edits
    [CM5IO.kicad_pcb, CM5_GPIO.kicad_sch, CM5_HighSpeed.kicad_sch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]
2026-03-09 PCB changes (many)
    [CM5IO.kicad_sch, CM5IO_archive.kicad_pcb, CM5IO_v2.kicad_pcb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]
2026-03-09 Update README with UI Panel communications protocol
    Added detailed documentation for the UI Panel communications protocol, including I2C functions for dials, auto/manual switch, and ON/OFF switch.
2026-03-09 Add image to ON/OFF switch section in README
    Added image to README for visual reference.
2026-03-16 pcb design
    [CM5IO.kicad_pcb]
2026-03-25 Added SPI code
2026-05-18 control panel etc data
    [Silverworm_Control_Panel-B_Cu.gbr, Silverworm_Control_Panel-B_Mask.gbr, Silverworm_Control_Panel-B_Paste.gbr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]
2026-05-19 conytrol panel
    [BOM-Silverworm_Control_Panel.csv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]
2026-05-19 motherboard layout
    [CM5IO.kicad_pcb, CM5IO_archive.kicad_pcb, CM5IO_dissassemled.kicad_pcb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]
2026-05-20 finalised motherboard
    [CM5_GPIO.kicad_sch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]
2026-05-23 pcb aaaaaaah
    [BOM-CM5IO.csv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]
2026-05-26 vib-coded UI virtual test base for esp32
2026-05-26 updated PID and SPi
2026-05-27 still working through GUI receiving speed from arduino board. WIP
2026-05-28 added functionality for arduino nano every
2026-05-28 fix on group As main.ino and some SPI read() function
    [app_state.py, motor_spi.py]
2026-05-28 Fix SPI slave framing and add REQUEST_SPEED handler (Group A)
    - Add onSSDeassert() interrupt: resets bufferIndex on SS rising edge so
    each RPi xfer2 transaction starts with a clean framing state; without
    this, unrecognised bytes left bufferIndex non-zero and subsequent
    commands were never recognised by the ISR
    - Add case '5' (REQUEST_SPEED): replies [0x31, speedL, speedH] so the
    RPi poll can read current encoder speed on demand
    - Add '5' to the 3-byte command-length table in the ISR
    - Remove unsolicited 100 ms speed report; speed is now sent only in
    response to an explicit REQUEST_SPEED from the RPi
    [Main.ino]
2026-05-28 fixed spi
2026-05-28 WIP start stop button flow, need to test
2026-05-28 Fix ESP32 I2C address in test script (0x55 → 0x08)
    [test_i2c_comms.py]
2026-05-28 most basic i2c tester
2026-05-28 changed spi
2026-05-28 mm/s, non-ascii comms, and motor speed feedback
2026-05-29 attempted motor feedback fix
    [main_window.py, motor_spi.py, test.py]
2026-05-29 spi port and light changes
2026-05-29 Add no-venv self-bootstrapping launcher for CM5 deployment
    - Root app.py checks for PyQt6/cv2/numpy; installs deps system-wide
    on first run (with --break-system-packages fallback for Debian),
    then re-execs so packages are visible before launching the GUI.
    - Fix interface/requirements.txt: add opencv-python and numpy,
    remove unused QT-PyQt-PySide-Custom-Widgets and pyinstaller.
    - Add silverworm.desktop for click-to-launch on the CM5.
    [app.py]
2026-05-29 Fix motor speed SPI feedback display
    [Main.ino, SpiSlave.cpp, app_state.py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]
2026-05-29 motor speed limits
2026-05-29 updated pid
2026-05-29 control panel i2c testing
2026-05-29 merging config fixes, and motor speed display GUI fixes into main
    [main_window.py]
2026-05-30 got both motors working! And enforced hard limits on motor value inputs
2026-05-30 SPI grp B test
2026-05-31 Fixed vibecoded RAM bomb problem + optimised a lot of the backend
    [main_window.py]
2026-05-31 Save recent recordings and do so for motor fault footage
2026-06-01 WIP, vibecoded hardware in loop test with guidance and also vibecoded automatic pitch control, manually coded telemetry data logs for data analytics in testing report. NOTE: will need to test if the 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
2026-06-01 spi testing
2026-06-08 UI changes
    [hil_run_20260604_195134.csv, hil_run_20260604_195413.csv, hil_run_20260604_200757.csv]
2026-06-09 Consolidate docs into README, untrack build artifacts
    - Merge CLAUDE.md into README: Group A/B/C, protocols, formulas, repo map
    - Make requirements-rpi.txt self-contained (one-command install on the Pi)
    - Add .gitignore + .gitattributes; untrack pyc/__pycache__/.DS_Store/logs/hil CSVs
    - Remove CLAUDE.md, CHANGELOG.md, README 2.md
    [hil_run_20260604_195134.csv, hil_run_20260604_195413.csv, hil_run_20260604_200757.csv]
2026-08-13 final things
    [CM5IO.kicad_pcb]

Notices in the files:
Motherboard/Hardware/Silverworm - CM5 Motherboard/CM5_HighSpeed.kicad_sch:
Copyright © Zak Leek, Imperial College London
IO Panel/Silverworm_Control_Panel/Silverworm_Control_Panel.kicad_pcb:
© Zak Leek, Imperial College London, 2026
